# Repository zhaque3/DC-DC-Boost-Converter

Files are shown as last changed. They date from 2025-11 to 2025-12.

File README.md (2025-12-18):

# DC Boost Board

**Project:** DC Boost Board — a programmable boost converter for the University of Alberta EcoCar 2025 Prototype Vehicle. The vehicle (Sally) won first place at the Shell Eco Marathon 2025 in the Hydrogen Fuel Cell Prototype Category. 

**Purpose:** This board takes the vehicle's hydrogen fuel cell output voltage (nominally 24 V) and provides a controllable boosted output (typical target: 48 V) for the motor controller and motor. It includes measurement (voltage/current sensing), safety/protection (eFuses and monitoring), an MCU running FreeRTOS for control and telemetry, a simple local UI (OLED + push buttons), and CAN bus communication with other boards on the vehicle and wireless base station.

<p align="center">
  
</p>

---

## Table of contents

1. [Key features](#key-features)
2. [Hardware details](#hardware-details)
3. [FreeRTOS firmware overview](#freertos-firmware-overview-what-is-actually-running-on-board)

---

## Key features

* **LM5123** synchronous boost controller driving external mosfets for high-efficiency boost operation.
* Programmable dynamic voltage tuning controlled by MCU and local UI.
* Input/Output: nominal 24 V. The board is designed to output 48V but is capable of outputting 57. 
* **Input / output voltage sensing** and **current sensing** using ADCs and filtering. Firmware computes averaged values before publishing them to the display and logs.
* **TPS2623 eFuses** for controlled power delivery and overcurrent protection.
* **Local UI**: small OLED display (SSD1306) + push buttons for interaction. The display shows input/output voltages, currents, and an effeciency score.
* **FreeRTOS-based firmware** with multiple tasks handling ADC acquisition, DAC control for the tracking/virtual voltage (TRK) pin, LED/status handling, screen updates, and CAN bus communication.

---

## Hardware details

### Synchronous boost controller

* The Texas Instruments LM5123 is used as the switching controller. It drives external mosfets located at the back of the board. The 4 high and low side mosfets can be place on this board. 
* The ENABLE pin from the boost controller is driven by the MCU to allow safe startup/shutdown sequences (the code waits until input voltage is above a small threshold, then toggles ENABLE with a startup delay).
* The TRK (tracking) reference to the controller is driven by the MCU DAC to set the desired output. The firmware converts the `SET_VOLT` value to an appropriate DAC code.

### Sensing

* Voltage sensing is implemented with resistor dividers feeding ADCs.
* Current sensing is performed by hall-effect current sensors that outputs an ADC value to the MCU. 
* ADC sampling is done via DMA for efficiency

### Microcontroller

* The board is built around an STM32G91KUE6 microcontroller, which serves as the central control, sensing, and communication unit for the boost system.
* The MCU runs a FreeRTOS-based firmware architecture, allowing concurrent handling of power control, sensing, UI updates, and CAN communication without blocking critical control paths.

---

## FreeRTOS firmware overview

The firmware running on the DC Boost Board is FreeRTOS based and implemented entirely in `app_freertos.c`.  
The system is structured as a set of independent FreeRTOS tasks, each responsible for a specific functional domain: power control, sensing, user interface, and vehicle communication.

## Tasks (as implemented in `app_freertos.c`)

### DefaultTask (`StartDefaultTask`)

- Initializes the USB CDC device at startup for debug telemetry.
- Implements ENABLE pin sequencing for the LM5123 boost controller:
  - Continuously monitors input voltage.
  - Applies a one-time startup delay before asserting ENABLE once sufficient input voltage is detected.
  - Forces ENABLE low if input voltage falls below threshold and resets the startup sequence.
- Handles a push-button input to increment the output voltage setpoint (`SET_VOLT`) with bounds checking based on input voltage.

### ADC Conversion Task (`StartAdcConv`)

- Starts **ADC peripherals with DMA** for continuous sampling.
- Measures:
  - Input voltage
  - Output voltage
  - Input current
  - Output current
- Applies a 50-sample moving average to current measurements for noise reduction.
- Computes a real-time efficiency estimate using measured voltage and current values.
- Publishes computed values into CAN data structures and prints debug telemetry over USB CDC.

### Screen Print Task (`startScreenPrint`)

- Drives an **SSD1306 OLED display**.
- Displays:
  - Voltage setpoint
  - Input and output voltages
  - Input and output currents
  - Computed efficiency
- When a fault or lock condition is received over CAN, the display switches to an alarm state.

### TRK Pin Control Task (`StartTRKPin`)

- Controls the LM5123 TRK (tracking) pin using the on-chip DAC.
- Converts `SET_VOLT` into a proportional DAC output corresponding to the desired boost output voltage.

### Status LED Task (`StartStatusLED`)

- Controls multiple PWM-driven status LEDs using STM32 timer peripherals.
- LED indications include:
  - Boost ENABLE state
  - General system activity
- Continuously monitors the ENABLE GPIO to synchronize LED states with actual hardware behavior.

## CAN Bus Communication

- Uses the STM32 FDCAN peripheral for vehicle network communication.
- CAN reception is interrupt-driven and handled via the RX FIFO callback, with received frames pushed into FreeRTOS message queues.
- A dedicated receive task parses incoming CAN messages to:
  - Detect fault or lock conditions (e.g. hydrogen alarm states).
  - Update system behavior and UI state.
- A dedicated transmit task periodically publishes:
  - Input and output voltages
  - Input and output currents
  - Efficiency
  - System status flags
- CAN messaging enables real-time monitoring by other PCB's on the vehicle and the wireless telemetry system.

---

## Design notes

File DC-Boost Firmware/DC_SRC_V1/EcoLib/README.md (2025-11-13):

# EcoLib
A repository for various drivers and helpful functions to utilize a range of peripherals throughout EcoCar electrical projects

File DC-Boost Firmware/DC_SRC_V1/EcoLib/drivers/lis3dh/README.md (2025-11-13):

Copy the lis3dh_conf.h into your local include folder and 
add the inc and src folders into your project. The conf 
file will allow you to select the appropriate stm series
header file and configure the proper i2c handle.

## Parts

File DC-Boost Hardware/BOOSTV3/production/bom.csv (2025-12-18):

Designator | Footprint | Quantity | Value | LCSC Part #
C1, C2, C3 | CAP_PAN_10X20_PAN | 3 | 470u
C10, C18, C20, C21, C22, C23, C24, C28, C34, C35, C36, C37, C38, C39, C40, C43 | 0603 | 16 | 100n
C11 | 0603 | 1 | 47u
C12 | 0805 | 1 | 220p
C13, C32, C41 | 0603 | 3 | 10n
C14 | 0603 | 1 | 12n
C15 | 0603 | 1 | 470p
C16, C55 | 0603 | 2 | 0u1
C17, C49, C50 | 0603 | 3 | 22u
C19, C33 | 0603 | 2 | 4u7
C25, C26, C27 | CAP_YX_16X31P5_RUB | 3 | 470u
C29, C30, C31 | 1210 | 3 | 10u
C4, C5, C6, C7 | 0805 | 4 | 22u
C42, C44, C47, C48, C53, C54, C8, C9 | 0603 | 8 | 1u
C45, C46 | 0603 | 2 | 10u
C51, C52 | 0603 | 2 | 2n2
D1, D19, D2, D20 | D_SOD_123_M | 4 | MMSZ5226B-7-F
D10, D15, D17, D5 | 0603 | 4 | Red
D11, D12, D13, D14, D7, D8 | 0603 | 6 | BLUE
D16, D18, D6, D9 | 0603 | 4 | Green
D21, D24 | SOT-23 | 2 | BAT54S
D22 | D_SOD-123 | 1 | MMSZ5266BT1G
D23 | D_SOD-123 | 1 | MMSZ5257BT1G
D3 | SOT95P280X145-6N | 1 | USBLC6-2SC6
D4 | 0603 | 1 | Orange
FB1 | 0603 | 1 | 300R
IC1 | SOT65P210X110-5N | 1 | ESDALC6V1W5
J3 | USB_C_Receptacle_GCT_USB4105-xx-A_16P_TopMnt_Horizontal | 1 | USB_C_Receptacle_USB2.0_14P
J4 | IDC-STM32-Prog-Header_2x05_P2.54mm_Vertical | 1 | STM32-Prog-Header
J5 | Display_128x64_096_I2C | 1 | OLED
L1 | 3u3_induc | 1 | 1u5
Q1, Q2, Q3, Q4 | SOT-23-3_Adjusted | 4 | SI2302A-TPMSCT-ND
R1 | 0603 | 1 | 50k
R10, R2, R9 | 0603 | 3 | 100k
R11 | 1u5_res_ | 1 | 1u5
R12 | 0603 | 1 | R
R13, R14, R15, R17, R18, R19 | 0603 | 6 | 220R
R16, R20, R21, R22, R23, R34, R35, R38, R39 | 0603 | 9 | 7.5k
R24 | 0603 | 1 | 10k
R25, R26, R28 | 0603 | 3 | 1k
R27 | 0603 | 1 | 8k
R29, R30, R31 | 0603 | 3 | 1k2
R3, R8 | 0603 | 2 | 200k
R32, R36 | 0603 | 2 | 12k
R33, R37 | 0603 | 2 | 30k
R4 | 0603 | 1 | 15.4k
R40, R41 | 0603 | 2 | 4k7
R42 | 0603 | 1 | 27k
R43 | 0603 | 1 | 3k
R44 | 0603 | 1 | 3k6
R45 | 0603 | 1 | 68k
R46, R47 | 0603 | 2 | 10
R48 | WSLP3921L7000FEA | 1 | 1u5
R5 | 0603 | 1 | 6k98
R6 | 0603 | 1 | 28k
R7 | 0603 | 1 | 25k
SW1, SW2 | PinHeader_1x03_P2.54mm_Vertical | 2 | SW_SPDT
SW3 | SW_PUSH_6mm_H5mm | 1 | RESET
SW4 | SW_PUSH_6mm_H5mm | 1 | O/P Voltage Adjust
U1, U12 | SOIC-8_3.9x4.9mm_P1.27mm | 2 | ACS713xLCTR-30A
U10, U11, U4, U5, U6, U7, U8, U9 | PowerMosDFNHybrid | 8 | NTMFS4D0N08XT1G
U13 | SOIC-8_3.9x4.9mm_P1.27mm | 1 | MCP2542FD
U14 | QFN-32-1EP_5x5mm_P0.5mm_EP3.45x3.45mm | 1 | STM32G491KEUx
U15 | SOT-223-3_TabPin2 | 1 | AZ1117IH-5.0
U16 | SOT-223-3_TabPin2 | 1 | AZ1117IH-3.3
U17, U18 | TI_SO-PowerPAD-8 | 2 | TPS259631
U19 | DB7W2-Male | 1 | ~
U2, U20 | SOIC-8_3.9x4.9mm_P1.27mm | 2 | MCP6007
U21, U22 | PowerPole15-45BoardEdge2x1 | 2 | ~
U3 | RGR0020C-MFG | 1 | LM51231QRGRRQ1
X1 | Crystal_SMD_3225-4Pin_3.2x2.5mm | 1 | OXETDLJANF-8MHZ

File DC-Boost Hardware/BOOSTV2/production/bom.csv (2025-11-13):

Designator | Footprint | Quantity | Value | LCSC Part #
C1, C2, C3 | CAP_PAN_10X20_PAN | 3 | 470u
C10, C18, C20, C21, C22, C23, C24, C28, C34, C35, C36, C37, C38, C39, C40, C43 | 0603 | 16 | 100n
C11 | 0603 | 1 | 330n
C12 | 0805 | 1 | 330p
C13, C32, C41 | 0603 | 3 | 10n
C14 | 0603 | 1 | 56n
C15 | 0603 | 1 | 470p
C16, C55 | 0603 | 2 | 0u1
C17, C49, C50 | 0603 | 3 | 22u
C19, C33 | 0603 | 2 | 4u7
C25, C26, C27 | CAP_YX_16X31P5_RUB | 3 | 470u
C29, C30, C31 | 1210 | 3 | 10u
C4, C5, C6, C7 | 0805 | 4 | 22u
C42, C44, C47, C48, C53, C54, C8, C9 | 0603 | 8 | 1u
C45, C46 | 0603 | 2 | 10u
C51, C52 | 0603 | 2 | 2n2
D1, D19, D2, D20 | D_SOD_123_M | 4 | MMSZ5226B-7-F
D10, D15, D17, D9 | 0603 | 4 | Red
D11, D12, D13, D14 | 0603 | 4 | BLUE
D16, D18 | 0603 | 2 | Green
D21, D24 | SOT-23 | 2 | BAT54S
D22 | D_SOD-123 | 1 | MMSZ5266BT1G
D23 | D_SOD-123 | 1 | MMSZ5257BT1G
D3 | SOT95P280X145-6N | 1 | USBLC6-2SC6
D4, D5, D6, D8 | 0603 | 4 | Amber
D7 | 0603 | 1 | LED
FB1 | 0603 | 1 | 300R
IC1 | SOT65P210X110-5N | 1 | ESDALC6V1W5
J1, J2 | PHOENIX_1017521 | 2 | PHNX_CONN_1017521
J3 | USB_C_Receptacle_GCT_USB4105-xx-A_16P_TopMnt_Horizontal | 1 | USB_C_Receptacle_USB2.0_14P
J4 | IDC-STM32-Prog-Header_2x05_P2.54mm_Vertical | 1 | STM32-Prog-Header
J5 | Display_128x64_096_I2C | 1 | OLED
L1 | L_Kemet_3u3 | 1 | MPXV1D2213L3R3
Q1, Q2, Q3, Q4 | SOT-23-3_Adjusted | 4 | SI2302A-TPMSCT-ND
R1 | 0603 | 1 | 221k
R10, R2, R9 | 0603 | 3 | 100k
R11 | CSS2H3920RL700F | 1 | 1m5
R12 | 0603 | 1 | R
R13, R14, R15, R17, R18, R19, R22, R23 | 0603 | 8 | 220R
R16 | 0603 | 1 | 140R
R20 | 0603 | 1 | 820
R21, R34, R35, R38, R39 | 0603 | 5 | 270
R24 | 0603 | 1 | 10k
R25, R26, R28 | 0603 | 3 | 1k
R27 | 0603 | 1 | 8k
R29, R30, R31 | 0603 | 3 | 1k2
R3, R8 | 0603 | 2 | 200k
R32, R36 | 0603 | 2 | 12k
R33, R37 | 0603 | 2 | 30k
R4 | 0603 | 1 | 5k
R40, R41 | 0603 | 2 | 4k7
R42 | 0603 | 1 | 27k
R43 | 0603 | 1 | 3k
R44 | 0603 | 1 | 3k6
R45 | 0603 | 1 | 68k
R46, R47 | 0603 | 2 | 10
R5 | 0603 | 1 | 6k98
R6 | 0603 | 1 | 28k
R7 | 0603 | 1 | 25k
SW1, SW2 | PinHeader_1x03_P2.54mm_Vertical | 2 | SW_SPDT
SW3 | SW_PUSH_6mm_H5mm | 1 | RESET
SW4 | SW_PUSH_6mm_H5mm | 1 | GPIO
U1, U12 | SOIC-8_3.9x4.9mm_P1.27mm | 2 | ACS713xLCTR-30A
U10, U11, U4, U5, U6, U7, U8, U9 | PowerMosDFNHybrid | 8 | NTMFS4D0N08XT1G
U13 | SOIC-8_3.9x4.9mm_P1.27mm | 1 | MCP2542FD
U14 | QFN-32-1EP_5x5mm_P0.5mm_EP3.45x3.45mm | 1 | STM32G491KEUx
U15 | SOT-223-3_TabPin2 | 1 | AZ1117IH-5.0
U16 | SOT-223-3_TabPin2 | 1 | AZ1117IH-3.3
U17, U18 | TI_SO-PowerPAD-8 | 2 | TPS259631
U19 | DB7W2-Male | 1 | ~
U2, U20 | SOIC-8_3.9x4.9mm_P1.27mm | 2 | MCP6007
U3 | RGR0020C-MFG | 1 | LM51231QRGRRQ1
X1 | Crystal_SMD_3225-4Pin_3.2x2.5mm | 1 | OXETDLJANF-8MHZ

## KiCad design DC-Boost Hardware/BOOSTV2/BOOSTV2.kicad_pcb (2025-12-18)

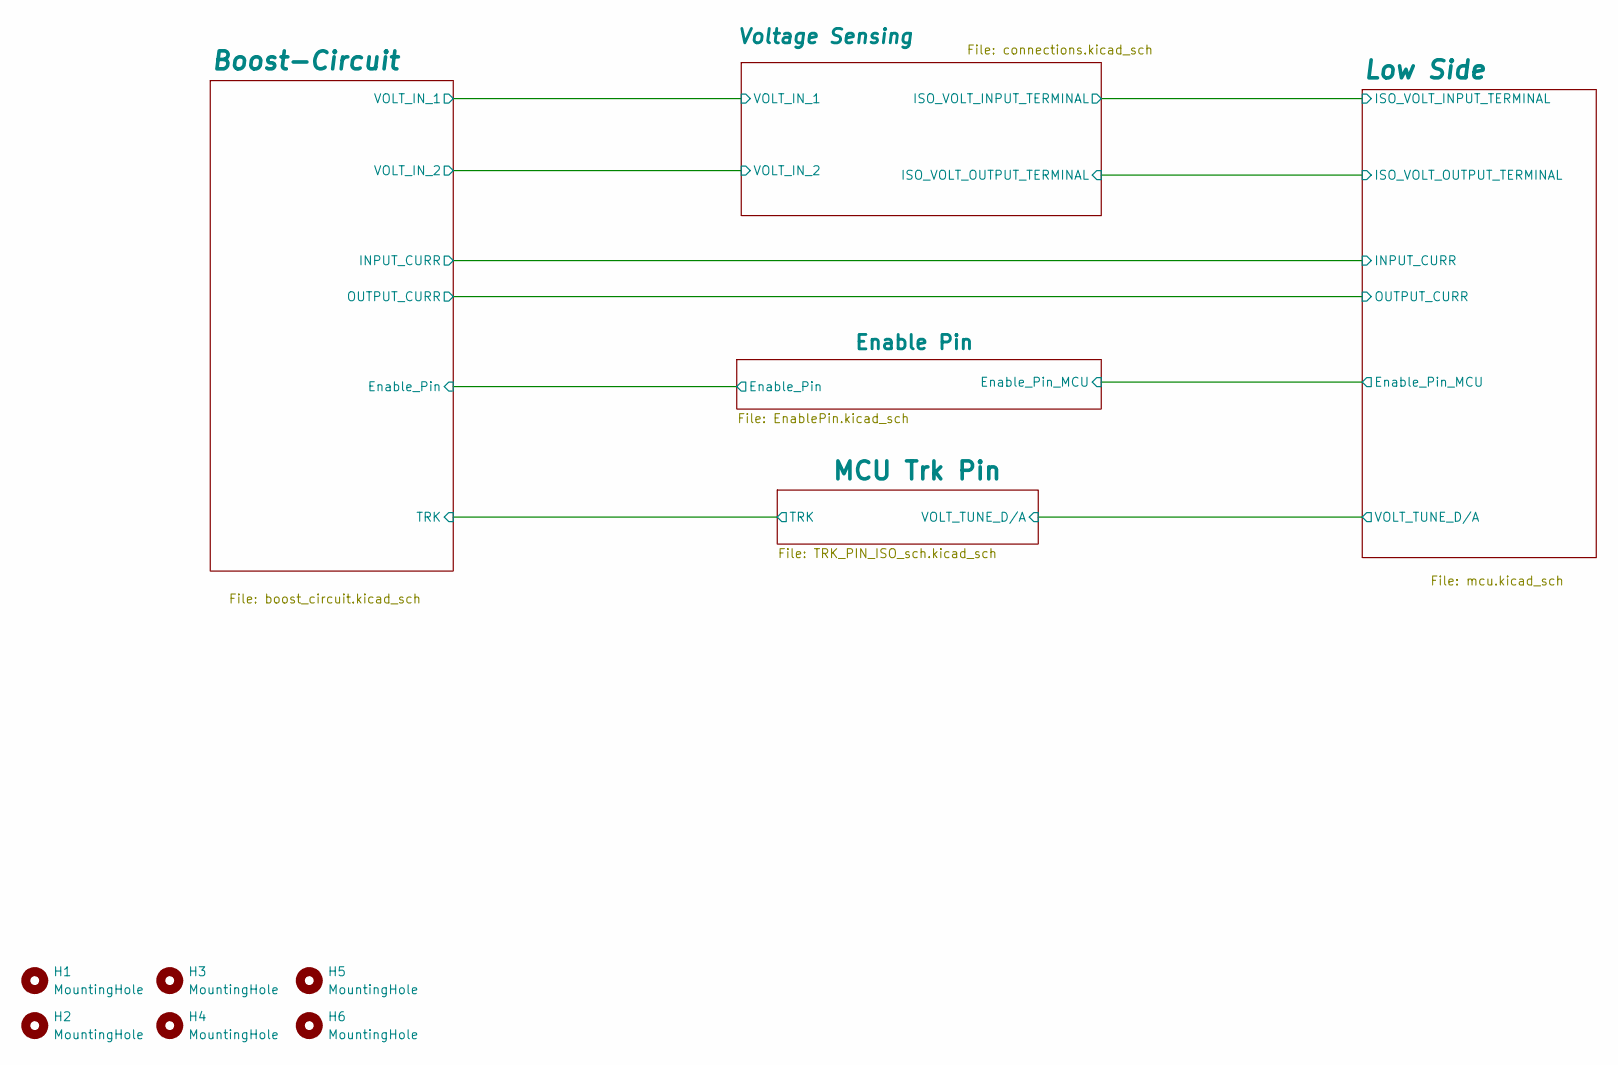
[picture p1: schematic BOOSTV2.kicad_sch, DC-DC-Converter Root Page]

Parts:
H1, H2, H3, H4, H5, H6: MountingHole; MountingHole_3.5mm

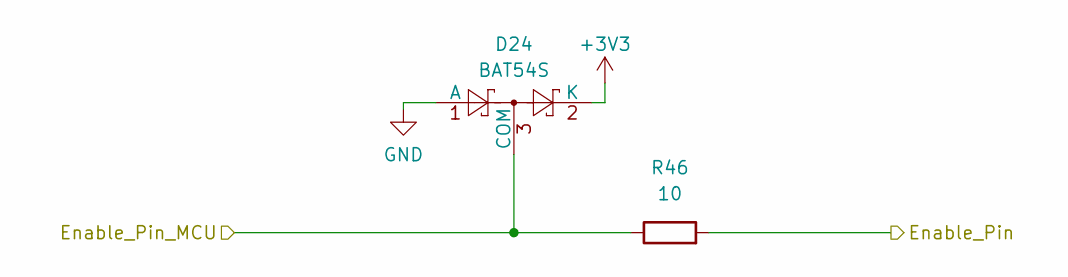
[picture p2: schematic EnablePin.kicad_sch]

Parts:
D24: BAT54S; SOT-23
R46: 10; R_0603_1608Metric

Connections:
+3V3: D24.2 (K); also elsewhere on the board
/Boost-Circuit/Enable_Pin: R46.2; also elsewhere on the board
/Enable Pin/Enable_Pin_MCU: D24.3 (COM), R46.1; also elsewhere on the board
GND: D24.1 (A); also elsewhere on the board

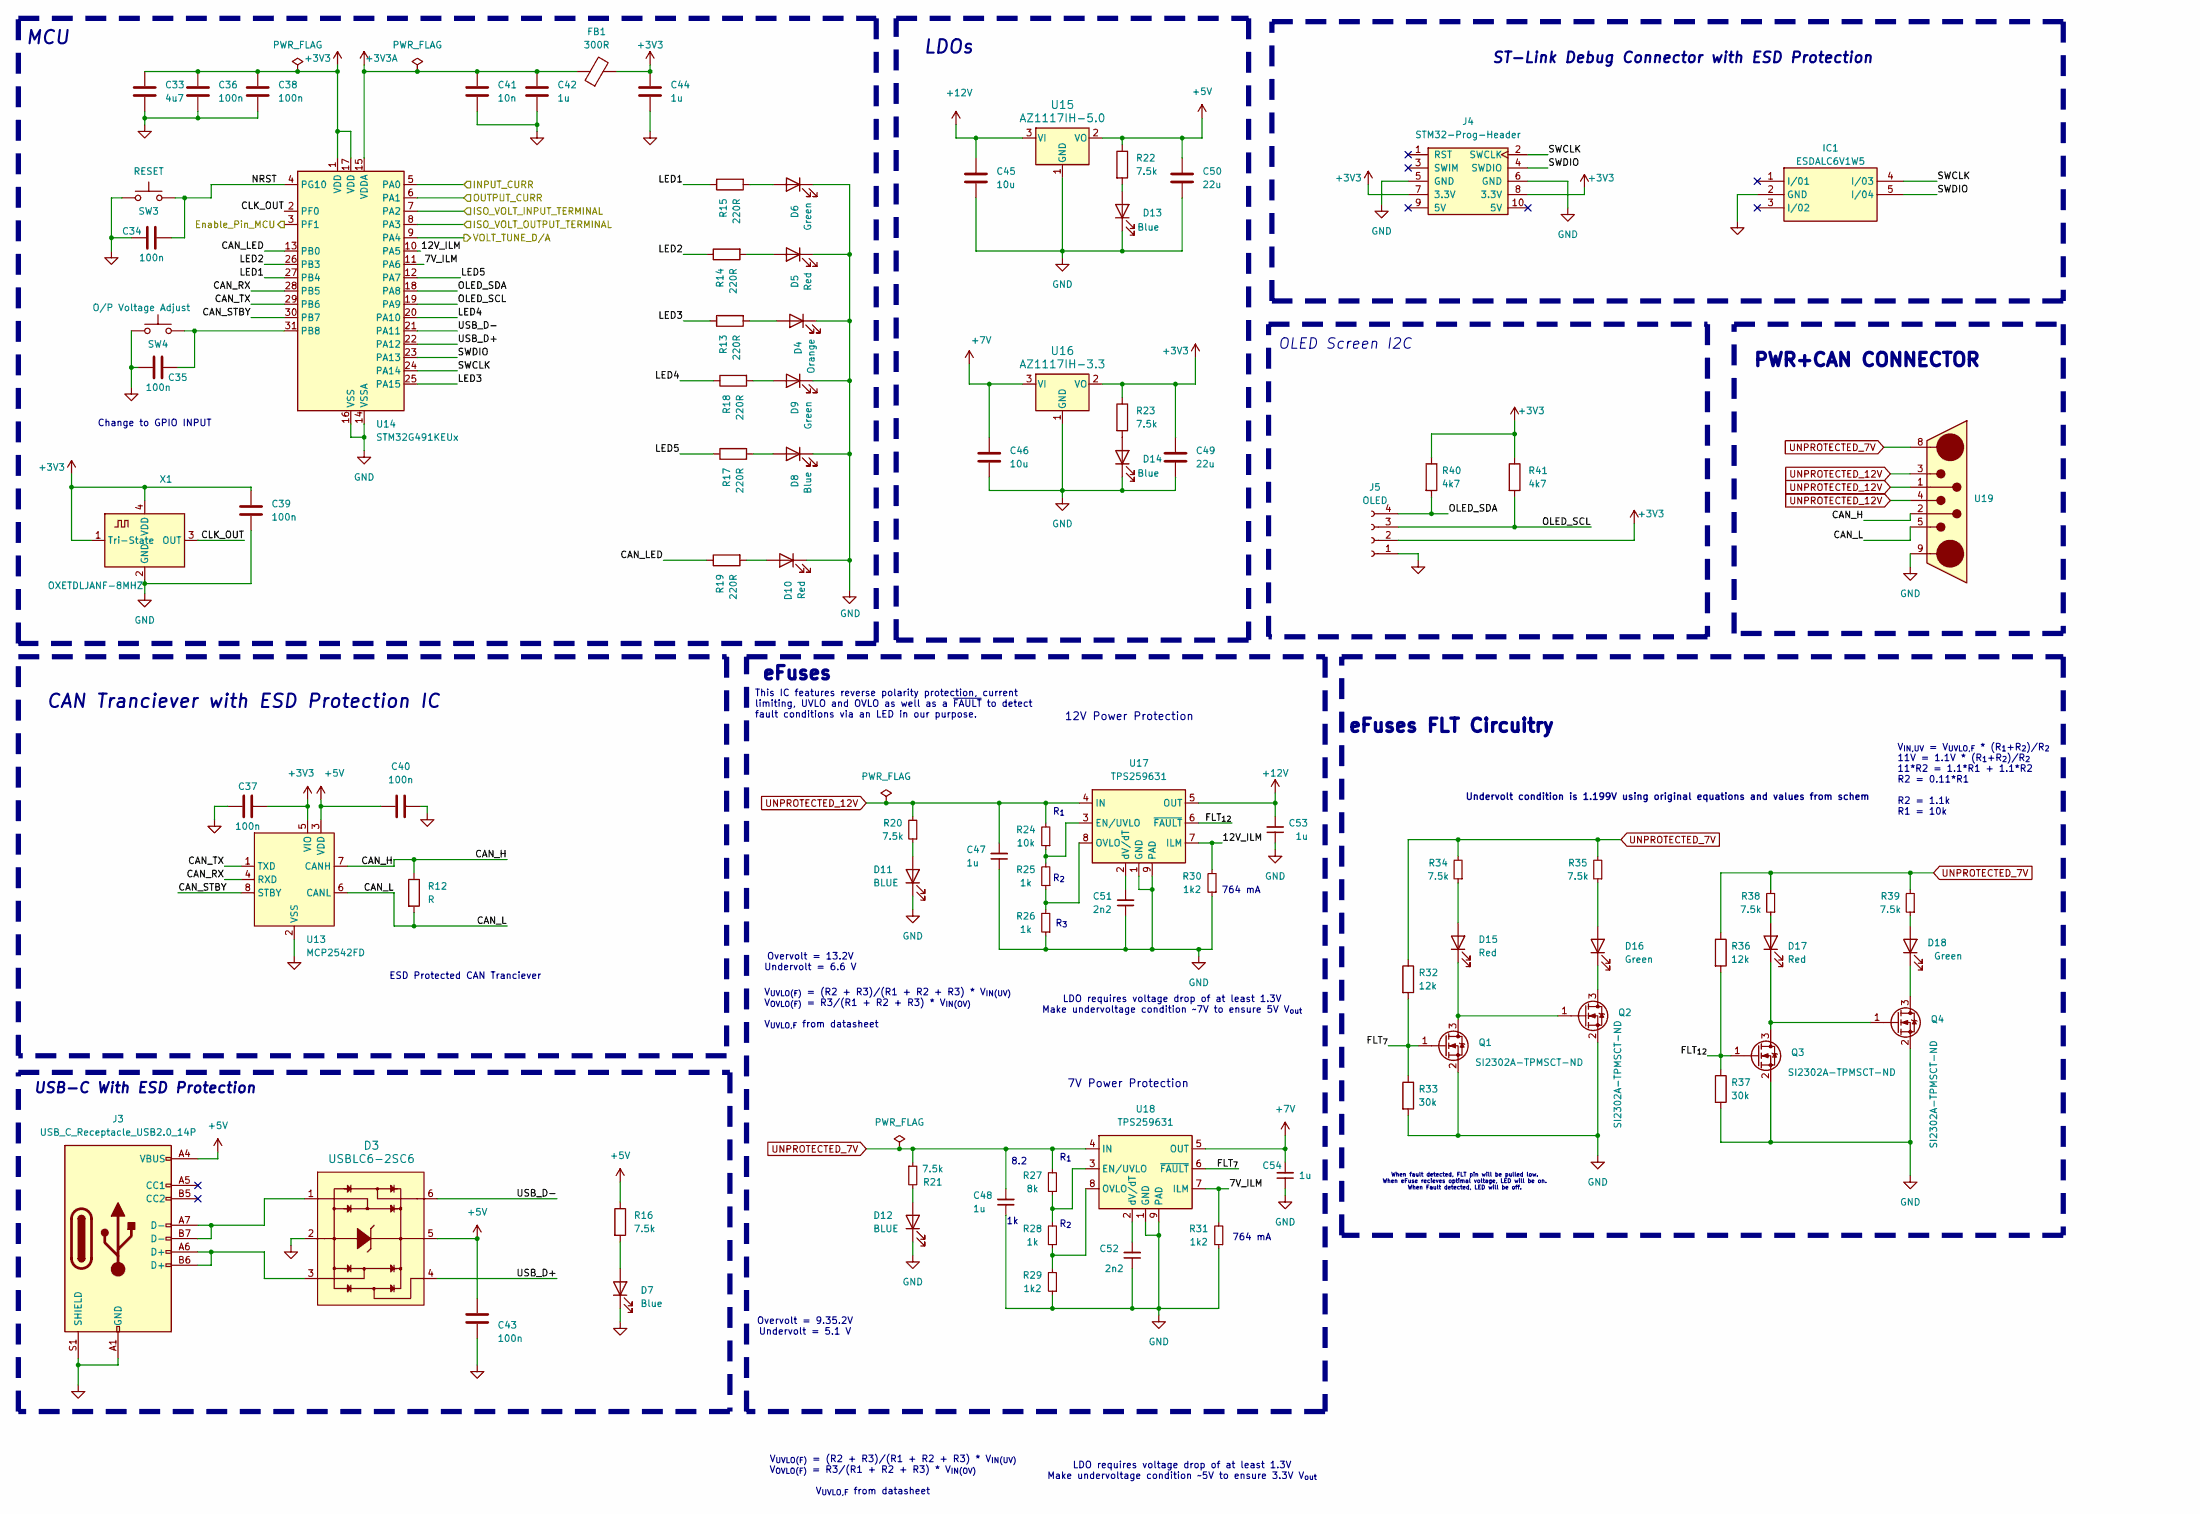
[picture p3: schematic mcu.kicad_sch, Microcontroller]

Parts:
C33: 4u7; C_0603_1608Metric; JLCPCB Part#(Optional) C96446
C34, C35, C36, C37, C38, C40, C43: 100n; C_0603_1608Metric; JLCPCB Part#(Optional) C1525
C39: 100n; C_0603_1608Metric
C41: 10n; C_0603_1608Metric; JLCPCB Part#(Optional) C96446
C42, C44: 1u; C_0603_1608Metric; JLCPCB Part#(Optional) C28323
C45, C46: 10u; C_0603_1608Metric
C47, C48, C53, C54: 1u; C_0603_1608Metric; Part# C15849
C49, C50: 22u; C_0603_1608Metric
C51, C52: 2n2; C_0603_1608Metric; Part# C1604
D3: USBLC6-2SC6; SOT95P280X145-6N; Digikey # 497-5235-1-ND
D4: Orange; LED_0603_1608Metric
D5, D10: Red; LED_0603_1608Metric
D6, D9: Green; LED_0603_1608Metric
D7, D8, D13, D14: Blue; LED_0603_1608Metric
D11, D12: BLUE; LED_0603_1608Metric; Part# C72041
D15, D17: Red; LED_0603_1608Metric; Part# C72043
D16, D18: Green; LED_0603_1608Metric; Part# C72043
FB1: 300R; L_0603_1608Metric; Digikey # 1934-1474-1-ND
IC1: ESDALC6V1W5; SOT65P210X110-5N; JLCPCB Part#(Optional) C2827626
J3: USB_C_Receptacle_USB2.0_14P; USB_C_Receptacle_GCT_USB4105-xx-A_16P_TopMnt_Horizontal
J4: STM32-Prog-Header; IDC-STM32-Prog-Header_2x05_P2.54mm_Vertical
J5: OLED; Display_128x64_096_I2C
Q1, Q2, Q3, Q4: SI2302A-TPMSCT-ND; SOT-23-3_Adjusted; Part# SI2302A-TPMSCT-ND
R12: R; R_0603_1608Metric
R13, R14, R15, R17, R18, R19: 220R; R_0603_1608Metric
R16, R22, R23: 7.5k; R_0603_1608Metric
R20: 7.5k; R_0603_1608Metric; Part# C23253
R21, R34, R35, R38, R39: 7.5k; R_0603_1608Metric; Part# C22966
R24: 10k; R_0603_1608Metric
R25, R26, R28: 1k; R_0603_1608Metric
R27: 8k; R_0603_1608Metric
R29, R30, R31: 1k2; R_0603_1608Metric
R32, R36: 12k; R_0603_1608Metric
R33, R37: 30k; R_0603_1608Metric
R40, R41: 4k7; R_0603_1608Metric
SW3: RESET; SW_PUSH_6mm_H5mm; Part # C2689510
SW4: O/P Voltage Adjust; SW_PUSH_6mm_H5mm; Part # C2689510
U13: MCP2542FD; SOIC-8_3.9x4.9mm_P1.27mm
U14: STM32G491KEUx; QFN-32-1EP_5x5mm_P0.5mm_EP3.45x3.45mm
U15: AZ1117IH-5.0; SOT-223-3_TabPin2
U16: AZ1117IH-3.3; SOT-223-3_TabPin2
U17, U18: TPS259631; TI_SO-PowerPAD-8
U19: DB7W2-Male
X1: OXETDLJANF-8MHZ; Crystal_SMD_3225-4Pin_3.2x2.5mm

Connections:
+3V3: C33.1, C36.1, C37.2, C38.1, C39.1, C44.1, C49.1, FB1.2, J4.7 (3.3V), J4.8 (3.3V), J5.2, R23.1, R40.1, R41.1, U13.5 (VIO), U14.1 (VDD), U14.17 (VDD), U16.2 (VO), X1.1 (Tri-State), X1.4 (VDD); also elsewhere on the board
+3V3A: C41.1, C42.1, FB1.1, U14.15 (VDDA)
+5V: C40.2, C43.2, C50.1, D3.5, J3.A4 (VBUS), J3.A9 (VBUS), J3.B4 (VBUS), J3.B9 (VBUS), R16.1, R22.1, U13.3 (VDD), U15.2 (VO); also elsewhere on the board
+7V: C46.1, C54.2, U16.3 (VI), U18.5 (OUT)
+12V: C45.1, C53.2, U15.3 (VI), U17.5 (OUT)
/Boost-Circuit/INPUT_CURR: U14.5 (PA0); also elsewhere on the board
/Boost-Circuit/OUTPUT_CURR: U14.6 (PA1); also elsewhere on the board
/Enable Pin/Enable_Pin_MCU: U14.3 (PF1); also elsewhere on the board
/Low Side/7V_ILM: R31.2, U14.11 (PA6), U18.7 (ILM)
/Low Side/12V_ILM: R30.2, U14.10 (PA5), U17.7 (ILM)
/Low Side/CAN_H: R12.1, U13.7 (CANH), U19.2
/Low Side/CAN_L: R12.2, U13.6 (CANL), U19.5
/Low Side/CAN_LED: R19.1, U14.13 (PB0)
/Low Side/CAN_RX: U13.4 (RXD), U14.28 (PB5)
/Low Side/CAN_STBY: U13.8 (STBY), U14.30 (PB7)
/Low Side/CAN_TX: U13.1 (TXD), U14.29 (PB6)
/Low Side/CLK_OUT: U14.2 (PF0), X1.3 (OUT)
/Low Side/FLT_{7}: Q1.1 (G), R32.2, R33.1, U18.6 (~FAULT)
/Low Side/FLT_{12}: Q3.1 (G), R36.2, R37.1, U17.6 (~FAULT)
/Low Side/ISO_VOLT_INPUT_TERMINAL: U14.7 (PA2); also elsewhere on the board
/Low Side/ISO_VOLT_OUTPUT_TERMINAL: U14.8 (PA3); also elsewhere on the board
/Low Side/LED1: R15.1, U14.27 (PB4)
/Low Side/LED2: R14.1, U14.26 (PB3)
/Low Side/LED3: R13.1, U14.25 (PA15)
/Low Side/LED4: R18.1, U14.20 (PA10)
/Low Side/LED5: R17.1, U14.12 (PA7)
/Low Side/NRST: C34.2, SW3.2, U14.4 (PG10)
/Low Side/OLED_SCL: J5.3, R41.2, U14.19 (PA9)
/Low Side/OLED_SDA: J5.4, R40.2, U14.18 (PA8)
/Low Side/SWCLK: IC1.4 (I/03), J4.2 (SWCLK), U14.24 (PA14)
/Low Side/SWDIO: IC1.5 (I/04), J4.4 (SWDIO), U14.23 (PA13)
/Low Side/USB_D+: D3.4, U14.22 (PA12)
/Low Side/USB_D-: D3.6, U14.21 (PA11)
/Low Side/VOLT_TUNE_D/A: U14.9 (PA4); also elsewhere on the board
GND: C33.2, C34.1, C35.1, C36.2, C37.1, C38.2, C39.2, C40.1, C41.2, C42.2, C43.1, C44.2, C45.2, C46.2, C47.1, C48.1, C49.2, C50.2, C51.1, C52.1, C53.1, C54.1, D3.2, D4.1 (K), D5.1 (K), D6.1 (K), D7.1 (K), D8.1 (K), D9.1 (K), D10.1 (K), D11.1 (K), D12.1 (K), D13.1 (K), D14.1 (K), IC1.2 (GND), J3.A1 (GND), J3.A12 (GND), J3.B1 (GND), J3.B12 (GND), J3.S1 (SHIELD), J4.5 (GND), J4.6 (GND), J5.1, Q1.2 (S), Q2.2 (S), Q3.2 (S), Q4.2 (S), R26.1, R29.1, R30.1, R31.1, R33.2, R37.2, SW3.1, SW4.2, U13.2 (VSS), U14.14 (VSSA), U14.16 (VSS), U14.32 (VSS), U14.33 (VSS), U15.1 (GND), U16.1 (GND), U17.1 (GND), U17.9 (PAD), U18.1 (GND), U18.9 (PAD), U19.9, X1.2 (GND); also elsewhere on the board
unnamed: D3.1, J3.A7 (D-), J3.B7 (D-)
unnamed: D3.3, J3.A6 (D+), J3.B6 (D+)
unnamed: D4.2 (A), R13.2
unnamed: D5.2 (A), R14.2
unnamed: D6.2 (A), R15.2
unnamed: D7.2 (A), R16.2
unnamed: D8.2 (A), R17.2
unnamed: D9.2 (A), R18.2
unnamed: D10.2 (A), R19.2
unnamed: D11.2 (A), R20.1
unnamed: D12.2 (A), R21.2
unnamed: D13.2 (A), R22.2
unnamed: D14.2 (A), R23.2
unnamed: D15.2 (A), R34.1
unnamed: D15.1 (K), Q1.3 (D), Q2.1 (G)
unnamed: D16.2 (A), R35.1
unnamed: D16.1 (K), Q2.3 (D)
unnamed: D17.2 (A), R38.1
unnamed: D17.1 (K), Q3.3 (D), Q4.1 (G)
unnamed: D18.2 (A), R39.1
unnamed: D18.1 (K), Q4.3 (D)
unnamed: C35.2, SW4.1, U14.31 (PB8)
unnamed: R24.1, R25.2, U17.3 (EN/UVLO)
unnamed: R25.1, R26.2, U17.8 (OVLO)
unnamed: C51.2, U17.2 (dV/dT)
unnamed: R27.1, R28.2, U18.3 (EN/UVLO)
unnamed: R28.1, R29.2, U18.8 (OVLO)
unnamed: C52.2, U18.2 (dV/dT)
UNPROTECTED_7V: C48.2, R21.1, R27.2, R32.1, R34.2, R35.2, R36.1, R38.2, R39.2, U18.4 (IN), U19.8
UNPROTECTED_12V: C47.2, R20.2, R24.2, U17.4 (IN), U19.1, U19.3, U19.4

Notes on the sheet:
764 mA
V_{UVLO(F)} = (R2 + R3)/(R1 + R2 + R3) * V_{IN(UV)} V_{OVLO(F)} = R3/(R1 + R2 + R3) * V_{IN(OV)} V_{UVLO,F} from datasheet
V_{IN,UV} = V_{UVLO,F} * (R_{1}+R_{2})/R_{2} 11V = 1.1V * (R_{1}+R_{2})/R_{2} 11*R2 = 1.1*R1 + 1.1*R2 R2 = 0.11*R1 R2 = 1.1k R1 = 10k
MCU
Undervolt condition is 1.199V using original equations and values from schem
LDO requires voltage drop of at least 1.3V Make undervoltage condition ~7V to ensure 5V V_{out}
Overvolt = 13.2V Undervolt = 6.6 V
PWR+CAN CONNECTOR
ST-Link Debug Connector with ESD Protection
8.2
USB-C With ESD Protection
R_{1}
LDOs
CAN Tranciever with ESD Protection IC
R_{2}
LDO requires voltage drop of at least 1.3V Make undervoltage condition ~5V to ensure 3.3V V_{out}
When fault detected, FLT pin will be pulled low. When eFuse recieves optimal voltage, LED will be on. When Fault detected, LED will be off.
Change to GPIO INPUT
eFuses
ESD Protected CAN Tranciever
This IC features reverse polarity protection, current limiting, UVLO and OVLO as well as a ~{FAULT} to detect fault conditions via an LED in our purpose.
V_{UVLO(F)} = (R2 + R3)/(R1 + R2 + R3) * V_{IN(UV)} V_{OVLO(F)} = R3/(R1 + R2 + R3) * V_{IN(OV)} V_{UVLO,F} from datasheet
Overvolt = 9.35.2V Undervolt = 5.1 V
7V Power Protection
OLED Screen I2C
R_{3}
12V Power Protection
eFuses FLT Circuitry

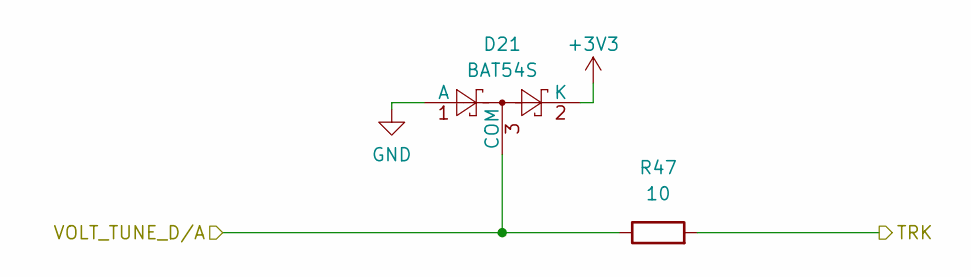
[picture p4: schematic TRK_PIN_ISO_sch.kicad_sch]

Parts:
D21: BAT54S; SOT-23
R47: 10; R_0603_1608Metric

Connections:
+3V3: D21.2 (K); also elsewhere on the board
/Boost-Circuit/TRK: R47.2; also elsewhere on the board
/Low Side/VOLT_TUNE_D/A: D21.3 (COM), R47.1; also elsewhere on the board
GND: D21.1 (A); also elsewhere on the board

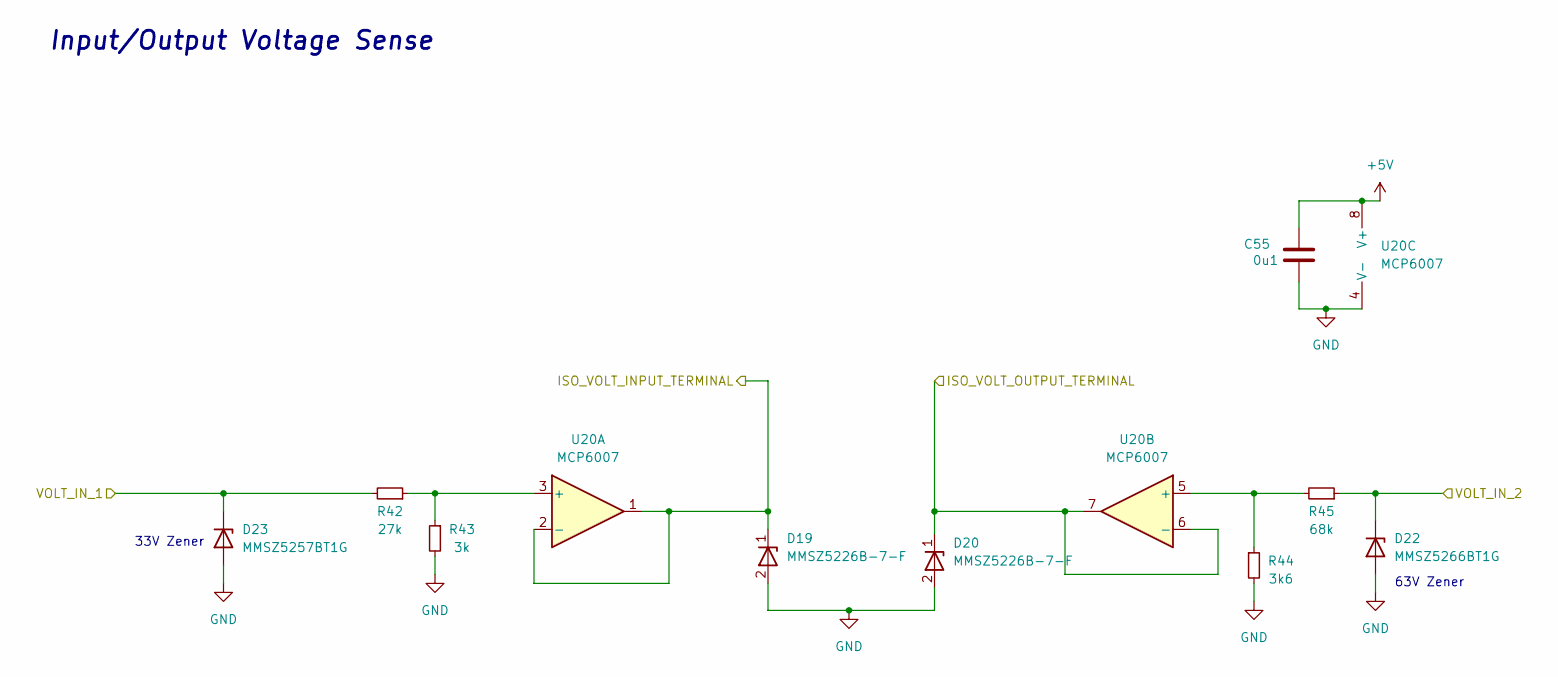
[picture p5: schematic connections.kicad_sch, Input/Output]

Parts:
C55: 0u1; C_0603_1608Metric
D19, D20: MMSZ5226B-7-F; D_SOD_123_M; Part# C155250
D22: MMSZ5266BT1G; D_SOD-123
D23: MMSZ5257BT1G; D_SOD-123
R42: 27k; R_0603_1608Metric
R43: 3k; R_0603_1608Metric; Part# C25811
R44: 3k6; R_0603_1608Metric
R45: 68k; R_0603_1608Metric
U20: MCP6007; SOIC-8_3.9x4.9mm_P1.27mm

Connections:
+5V: C55.1, U20.8 (V+); also elsewhere on the board
/Boost-Circuit/VOLT_IN_1: D23.1 (K), R42.2; also elsewhere on the board
/Boost-Circuit/VOLT_IN_2: D22.1 (K), R45.1; also elsewhere on the board
/Low Side/ISO_VOLT_INPUT_TERMINAL: D19.1, U20.1, U20.2 (-); also elsewhere on the board
/Low Side/ISO_VOLT_OUTPUT_TERMINAL: D20.1, U20.6 (-), U20.7; also elsewhere on the board
GND: C55.2, D19.2, D20.2, D22.2 (A), D23.2 (A), R43.2, R44.2, U20.4 (V-); also elsewhere on the board
unnamed: R42.1, R43.1, U20.3 (+)
unnamed: R44.1, R45.2, U20.5 (+)

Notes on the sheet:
33V Zener
Input/Output Voltage Sense
63V Zener

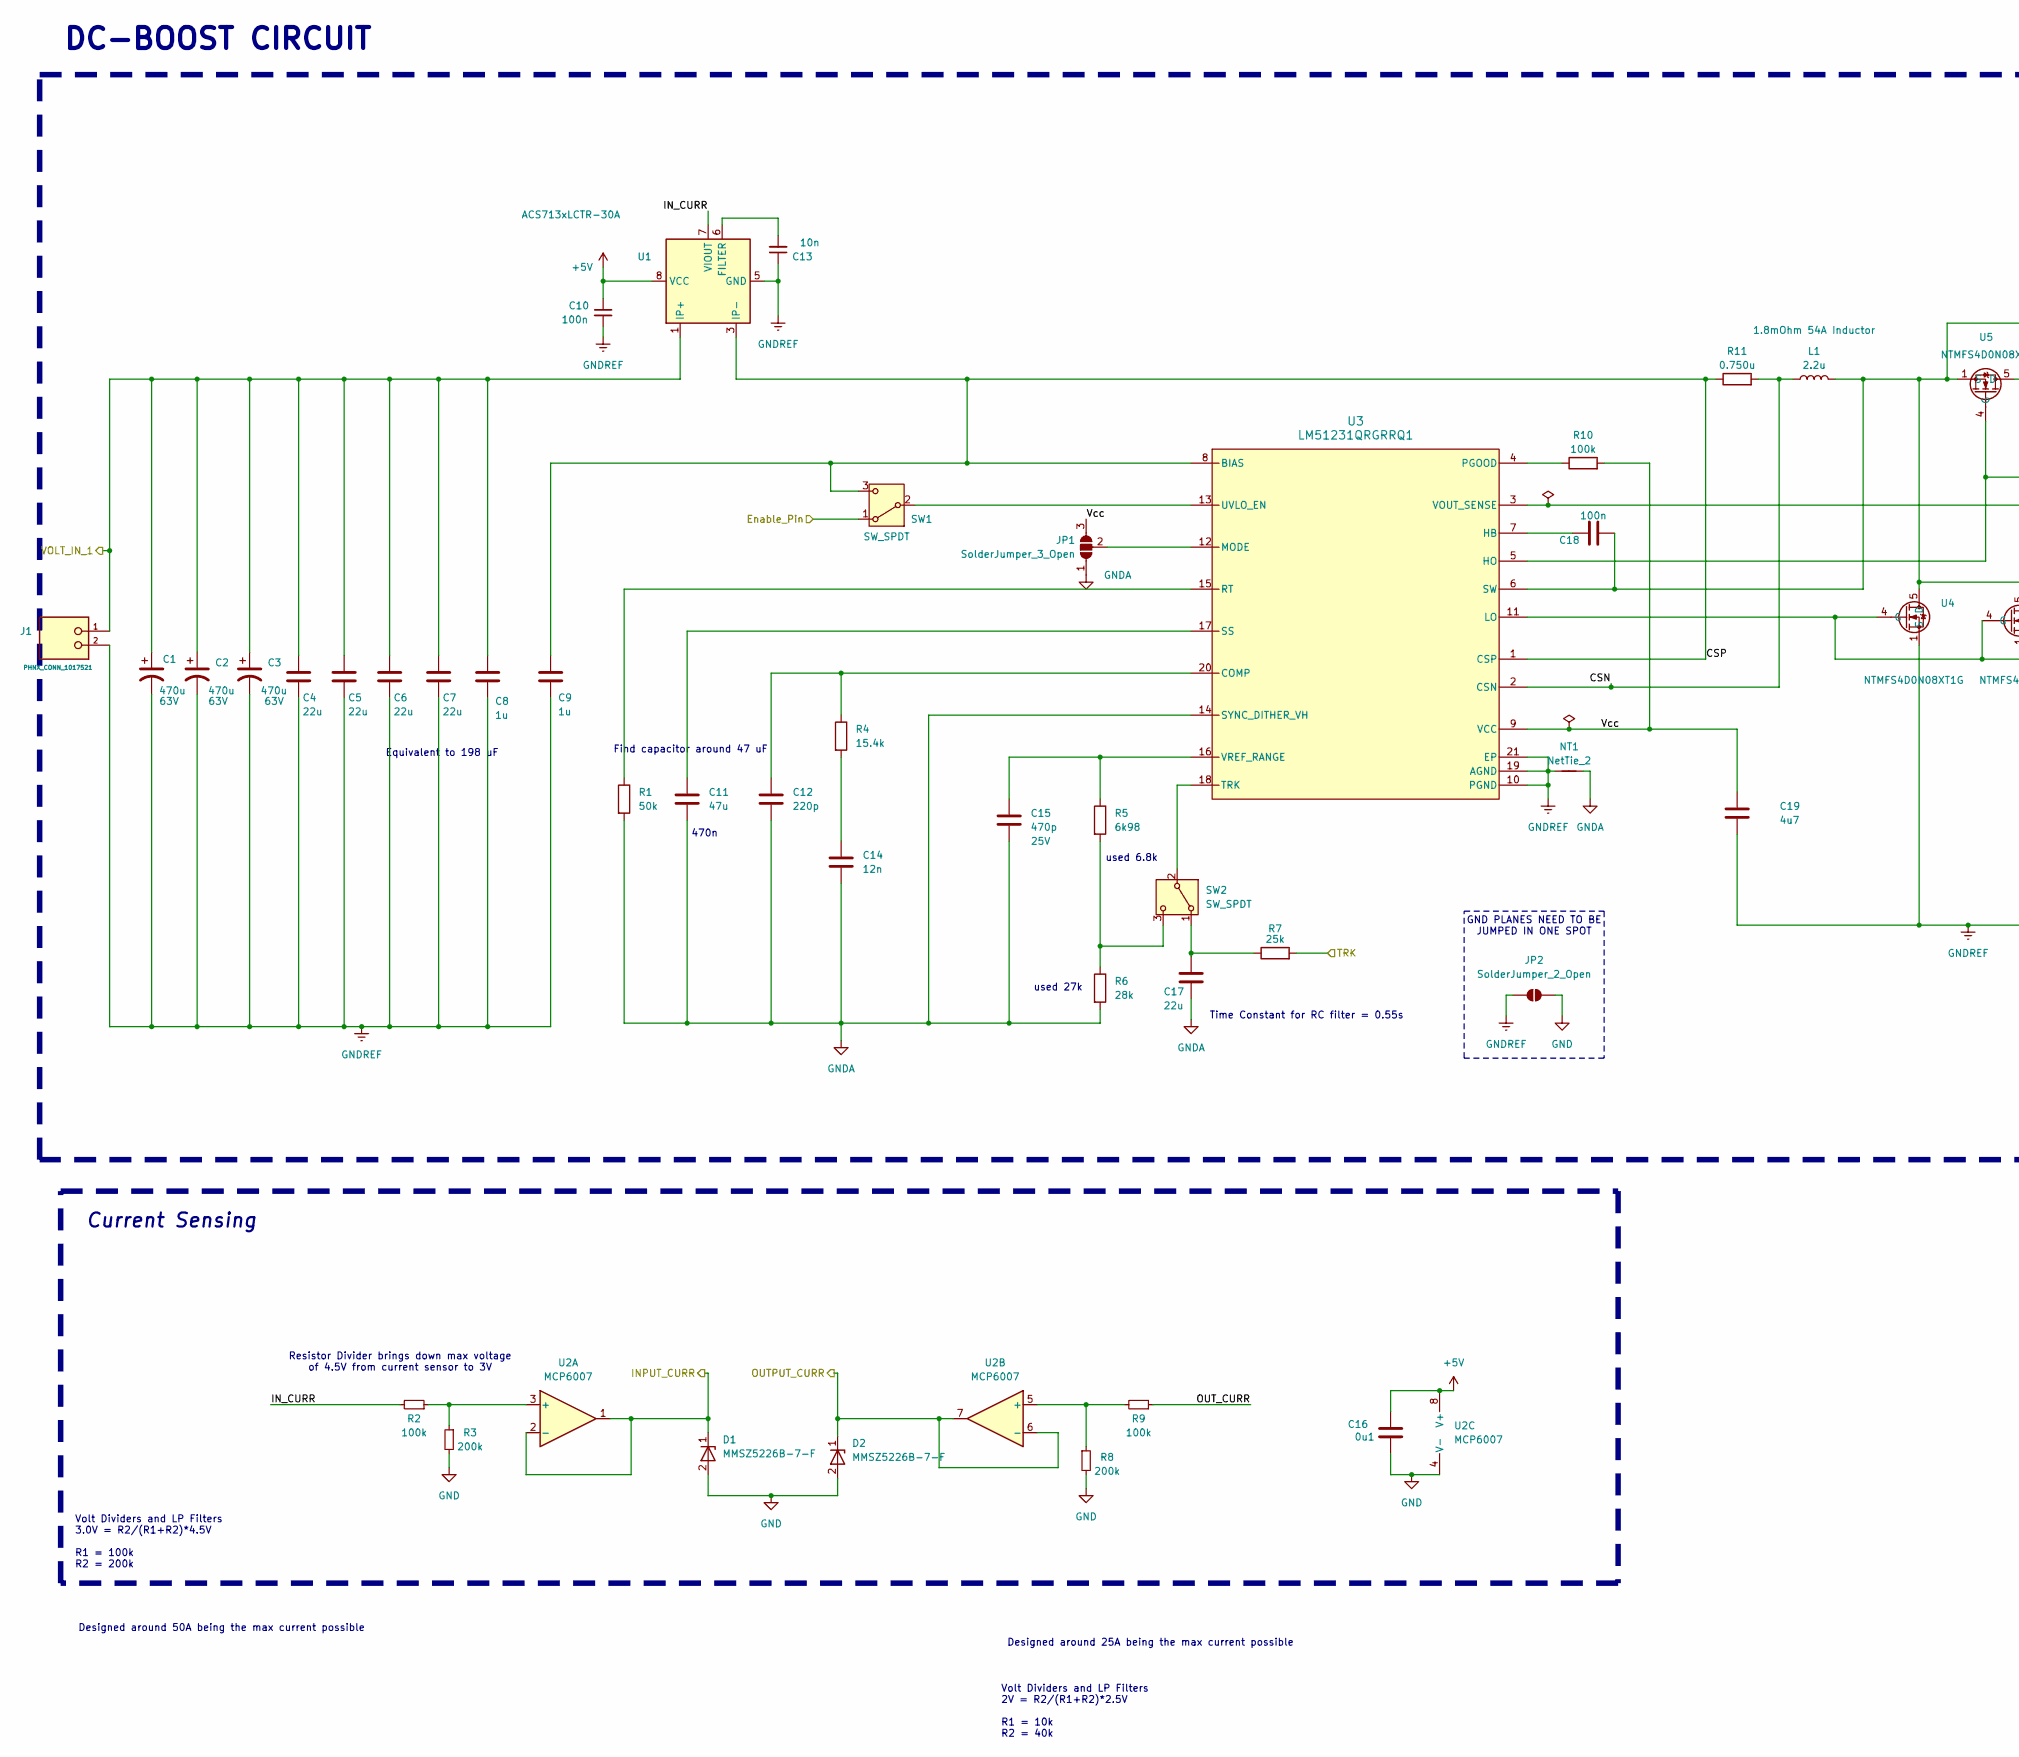
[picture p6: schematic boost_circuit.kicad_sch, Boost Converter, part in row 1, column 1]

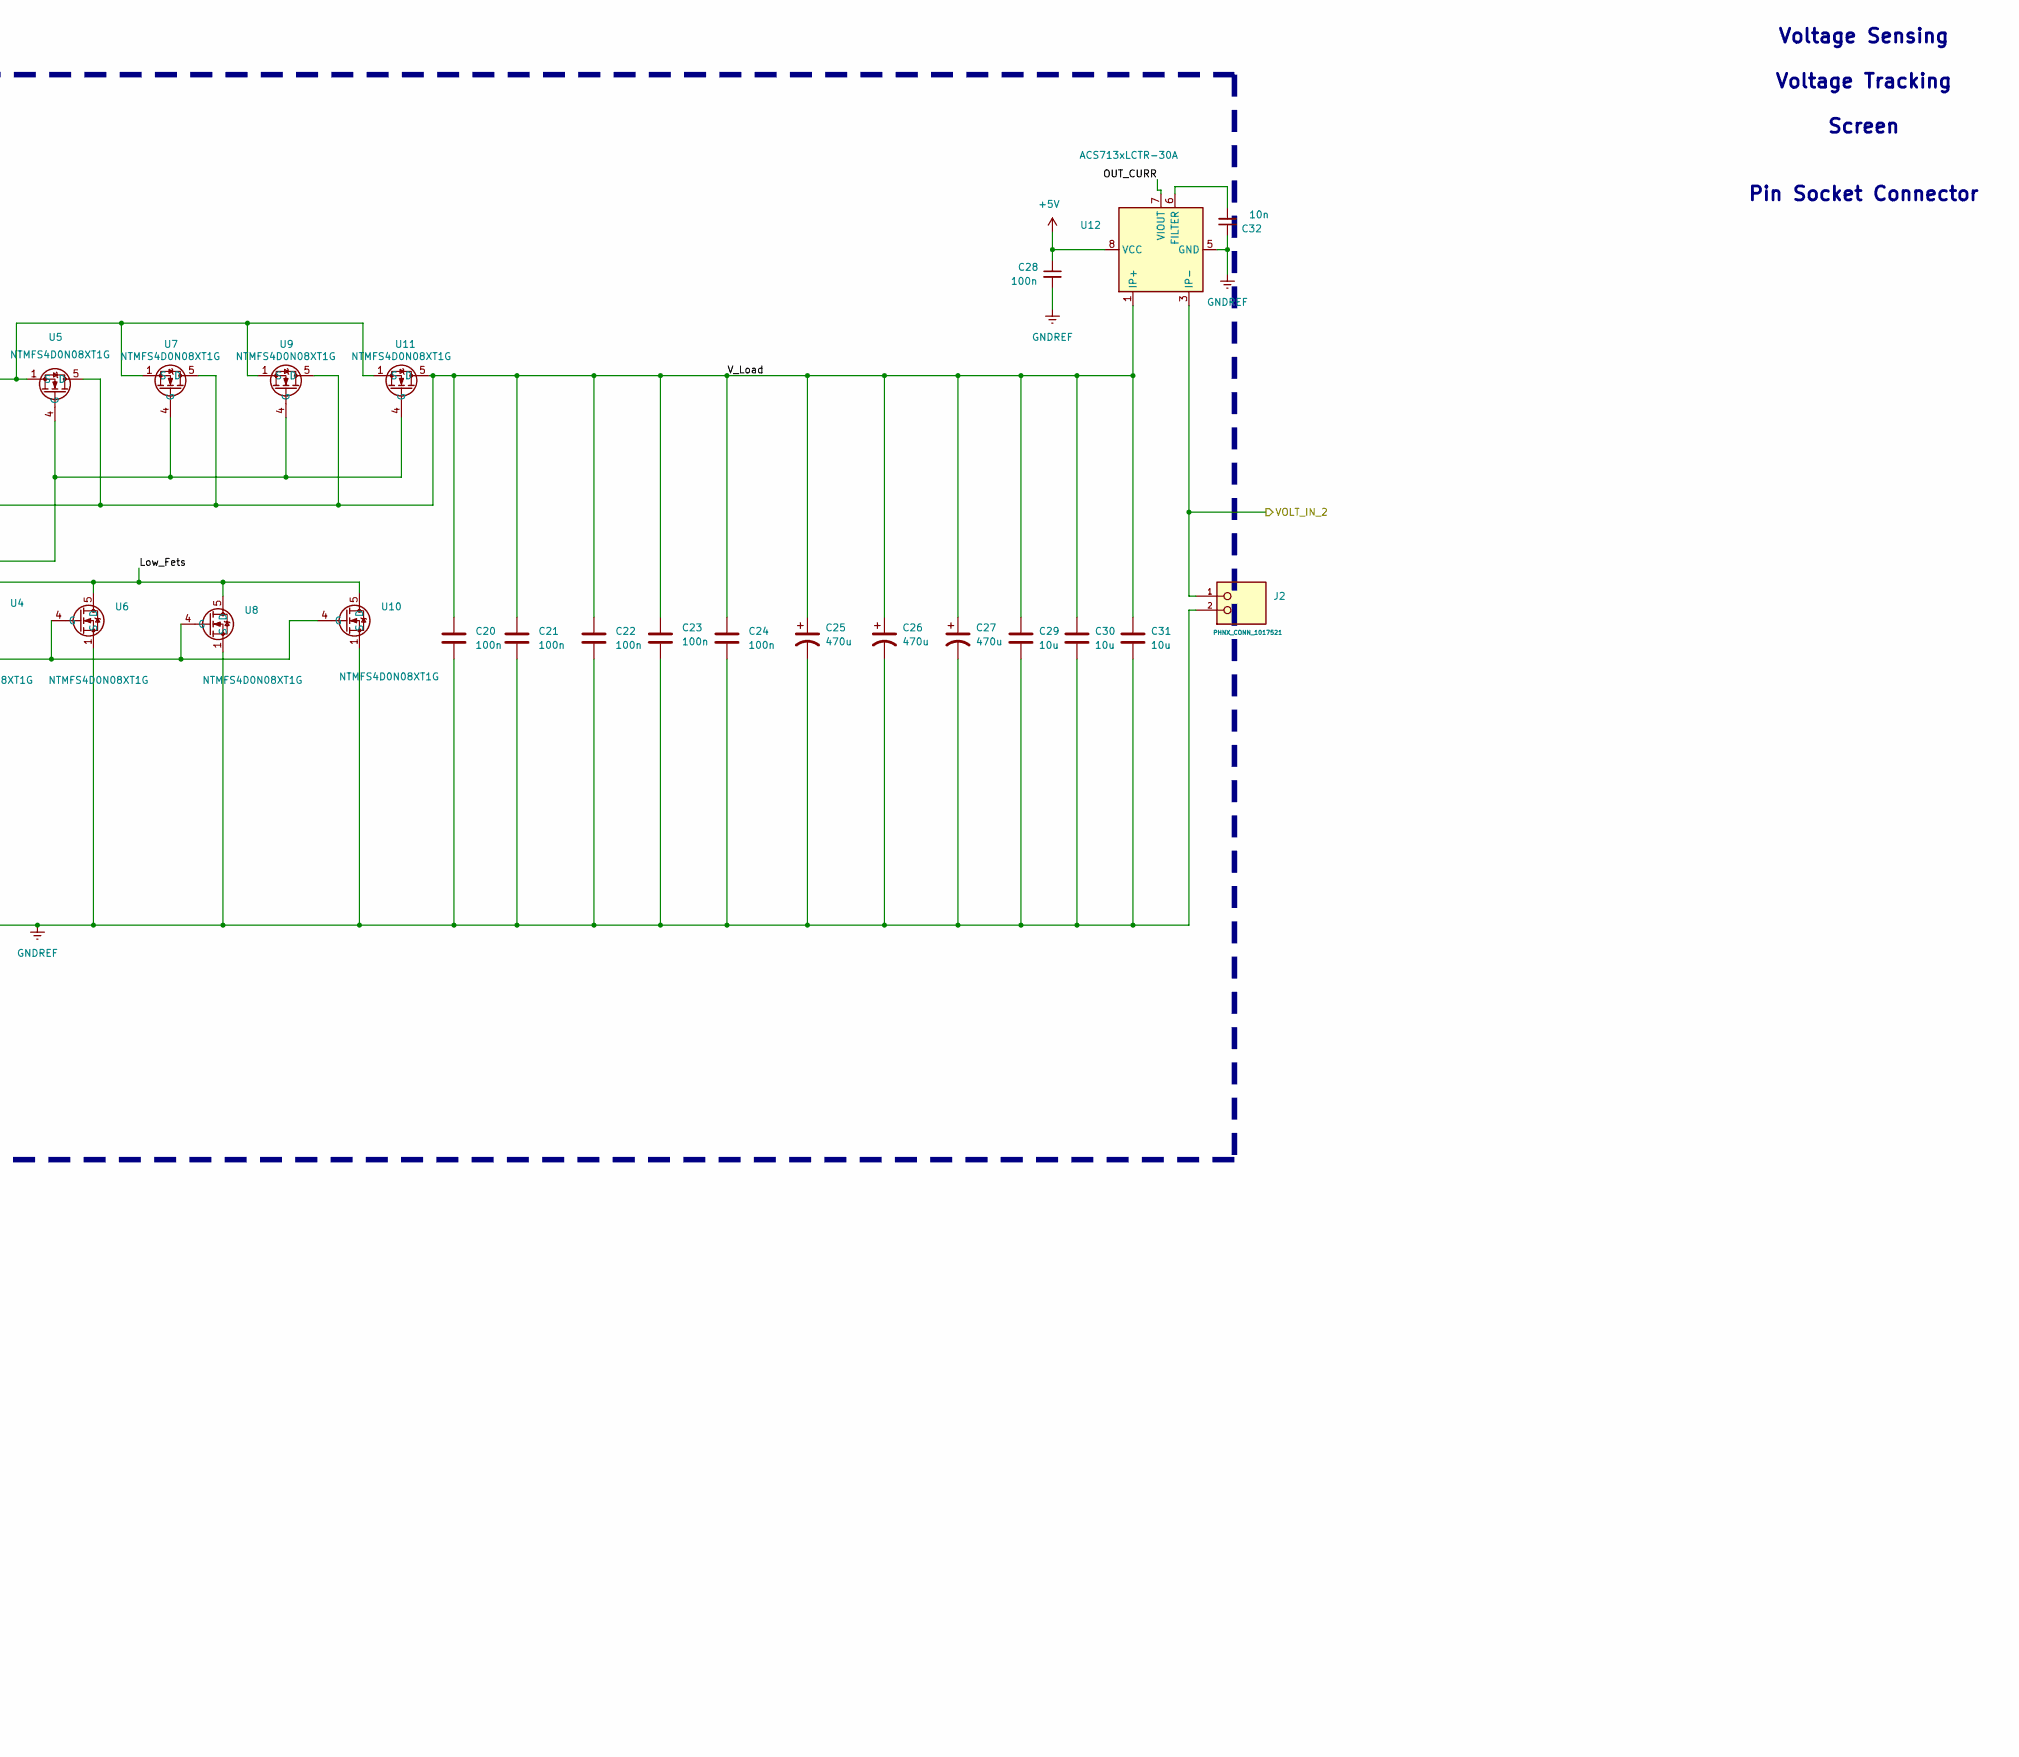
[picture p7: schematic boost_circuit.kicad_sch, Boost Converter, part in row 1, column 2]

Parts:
C1, C2, C3: 470u; CAP_PAN_10X20_PAN; Part # ECA-1HM471B
C4, C5, C6, C7: 22u; C_0805_2012Metric
C8, C9: 1u; C_0603_1608Metric
C10, C28: 100n; C_0603_1608Metric; Part# C88219
C11: 47u; C_0603_1608Metric
C12: 220p; C_0805_2012Metric
C13, C32: 10n; C_0603_1608Metric; Part# C88219
C14: 12n; C_0603_1608Metric
C15: 470p; C_0603_1608Metric; Rating 25V
C16: 0u1; C_0603_1608Metric
C17: 22u; C_0603_1608Metric
C18: 100n; R_0603_1608Metric
C19: 4u7; C_0603_1608Metric
C20, C21, C22, C23, C24: 100n; C_0603_1608Metric
C25, C26, C27: 470u; CAP_YX_16X31P5_RUB; Part # 100ZLH470MEFC16X31.5
C29, C30, C31: 10u; C_1210_3225Metric
D1, D2: MMSZ5226B-7-F; D_SOD_123_M; Part# C155250
J1, J2: PHNX_CONN_1017521; PHOENIX_1017521; PARTREV 04.01.2018
JP1: SolderJumper_3_Open; SolderJumper-3_P1.3mm_Open_RoundedPad1.0x1.5mm_NumberLabels
JP2: SolderJumper_2_Open; SolderJumper-2_P1.3mm_Open_RoundedPad1.0x1.5mm
L1: 2.2u; L_Kemet_3u3
NT1: NetTie_2; NetTie-2_SMD_Pad0.5mm
R1: 50k; R_0603_1608Metric
R2, R9, R10: 100k; R_0603_1608Metric
R3: 200k; R_0603_1608Metric; Part# C25811
R4: 15.4k; R_0603_1608Metric_Pad0.98x0.95mm_HandSolder
R5: 6k98; R_0603_1608Metric
R6: 28k; R_0603_1608Metric
R7: 25k; R_0603_1608Metric
R8: 200k; R_0603_1608Metric
R11: 0.750u; CSS2H3920RL700F
SW1, SW2: SW_SPDT; PinHeader_1x03_P2.54mm_Vertical
U1, U12: ACS713xLCTR-30A; SOIC-8_3.9x4.9mm_P1.27mm
U2: MCP6007; SOIC-8_3.9x4.9mm_P1.27mm
U3: LM51231QRGRRQ1; RGR0020C-MFG
U4, U5, U6, U7, U8, U9, U10, U11: NTMFS4D0N08XT1G; PowerMosDFNHybrid

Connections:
+5V: C10.1, C16.1, C28.1, U1.8 (VCC), U2.8 (V+), U12.8 (VCC); also elsewhere on the board
/Boost-Circuit/CSN: L1.1, R11.2, U3.2 (CSN)
/Boost-Circuit/CSP: C9.1, R11.1, SW1.3 (C), U1.3 (IP-), U1.4 (IP-), U3.1 (CSP), U3.8 (BIAS)
/Boost-Circuit/Enable_Pin: SW1.1 (A); also elsewhere on the board
/Boost-Circuit/INPUT_CURR: D1.1, U2.1, U2.2 (-); also elsewhere on the board
/Boost-Circuit/IN_CURR: R2.2, U1.7 (VIOUT)
/Boost-Circuit/Low_Fets: C18.1, L1.2, U3.6 (SW), U4.5 (D), U5.1 (S), U5.2 (S), U5.3 (S), U6.5 (D), U7.1 (S), U7.2 (S), U7.3 (S), U8.5 (D), U9.1 (S), U9.2 (S), U9.3 (S), U10.5 (D), U11.1 (S), U11.2 (S), U11.3 (S)
/Boost-Circuit/OUTPUT_CURR: D2.1, U2.6 (-), U2.7; also elsewhere on the board
/Boost-Circuit/OUT_CURR: R9.1, U12.7 (VIOUT)
/Boost-Circuit/TRK: R7.2; also elsewhere on the board
/Boost-Circuit/VOLT_IN_1: C1.1, C2.1, C3.1, C4.1, C5.1, C6.1, C7.1, C8.1, J1.1, U1.1 (IP+), U1.2 (IP+); also elsewhere on the board
/Boost-Circuit/VOLT_IN_2: J2.1, U12.3 (IP-), U12.4 (IP-); also elsewhere on the board
/Boost-Circuit/V_Load: C20.1, C21.1, C22.1, C23.1, C24.1, C25.1, C26.1, C27.1, C29.1, C30.1, C31.1, U3.3 (VOUT_SENSE), U5.5 (D), U7.5 (D), U9.5 (D), U11.5 (D), U12.1 (IP+), U12.2 (IP+)
/Boost-Circuit/Vcc: C19.1, JP1.3 (B), R10.2, U3.9 (VCC)
GND: C16.2, D1.2, D2.2, JP2.2 (B), R3.2, R8.2, U2.4 (V-); also elsewhere on the board
GNDA: C11.2, C12.2, C14.2, C15.2, C17.2, JP1.1 (A), NT1.2, R1.2, R6.2, U3.14 (SYNC_DITHER_VH)
GNDREF: C1.2, C2.2, C3.2, C4.2, C5.2, C6.2, C7.2, C8.2, C9.2, C10.2, C13.1, C19.2, C20.2, C21.2, C22.2, C23.2, C24.2, C25.2, C26.2, C27.2, C28.2, C29.2, C30.2, C31.2, C32.1, J1.2, J2.2, JP2.1 (A), NT1.1, U1.5 (GND), U3.10 (PGND), U3.19 (AGND), U3.21 (EP), U4.1 (S), U4.2 (S), U4.3 (S), U6.1 (S), U6.2 (S), U6.3 (S), U8.1 (S), U8.2 (S), U8.3 (S), U10.1 (S), U10.2 (S), U10.3 (S), U12.5 (GND)
unnamed: C14.1, R4.2
unnamed: JP1.2 (C), U3.12 (MODE)
unnamed: SW1.2 (B), U3.13 (UVLO_EN)
unnamed: C17.1, R7.1, SW2.1 (A)
unnamed: SW2.2 (B), U3.18 (TRK)
unnamed: R5.2, R6.1, SW2.3 (C)
unnamed: C13.2, U1.6 (FILTER)
unnamed: R2.1, R3.1, U2.3 (+)
unnamed: R8.1, R9.2, U2.5 (+)
unnamed: C12.1, R4.1, U3.20 (COMP)
unnamed: C18.2, U3.7 (HB)
unnamed: R10.1, U3.4 (PGOOD)
unnamed: R1.1, U3.15 (RT)
unnamed: C11.1, U3.17 (SS)
unnamed: C15.1, R5.1, U3.16 (VREF_RANGE)
unnamed: U3.11 (LO), U4.4 (G), U6.4 (G), U8.4 (G), U10.4 (G)
unnamed: U3.5 (HO), U5.4 (G), U7.4 (G), U9.4 (G), U11.4 (G)
unnamed: C32.2, U12.6 (FILTER)

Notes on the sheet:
used 27k
DC-BOOST CIRCUIT
Resistor Divider brings down max voltage of 4.5V from current sensor to 3V
470n
used 6.8k
Volt Dividers and LP Filters 3.0V = R2/(R1+R2)*4.5V R1 = 100k R2 = 200k
Time Constant for RC filter = 0.55s
Volt Dividers and LP Filters 2V = R2/(R1+R2)*2.5V R1 = 10k R2 = 40k
Current Sensing
GND PLANES NEED TO BE JUMPED IN ONE SPOT
Voltage Sensing Voltage Tracking Screen Pin Socket Connector
Designed around 25A being the max current possible
Find capacitor around 47 uF
Designed around 50A being the max current possible
Equivalent to 198 uF

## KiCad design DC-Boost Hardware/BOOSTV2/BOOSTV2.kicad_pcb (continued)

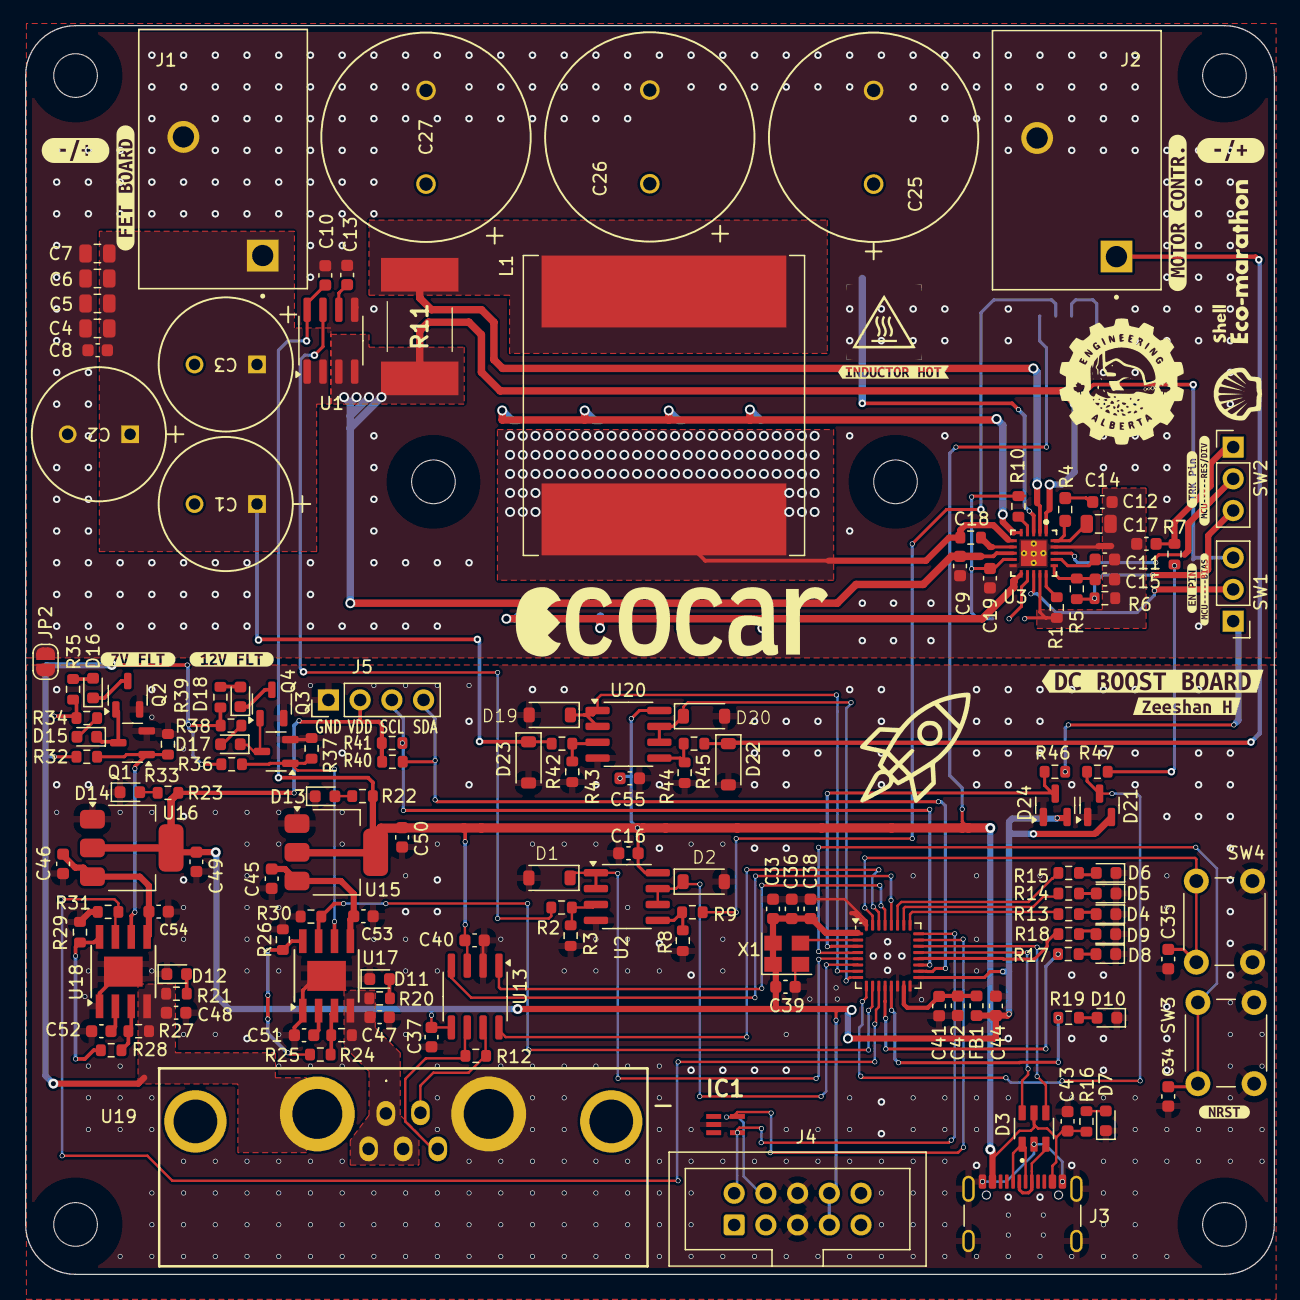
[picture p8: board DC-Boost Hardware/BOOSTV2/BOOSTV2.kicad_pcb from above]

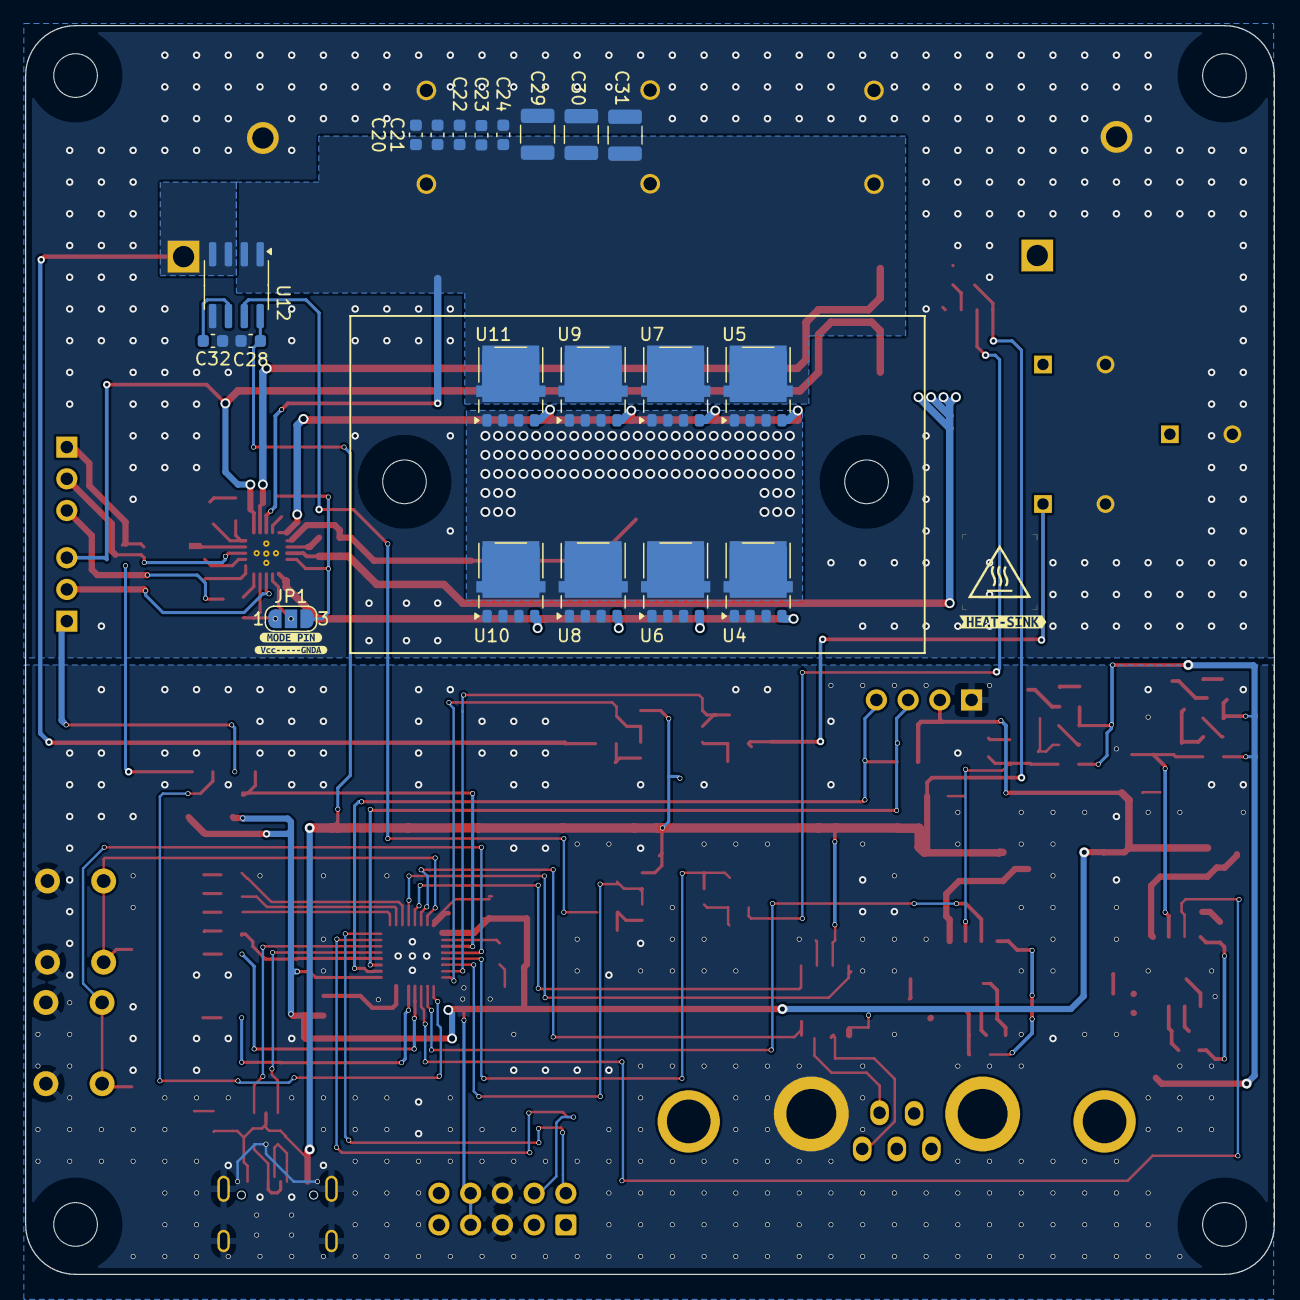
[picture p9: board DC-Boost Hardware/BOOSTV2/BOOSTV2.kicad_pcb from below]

Board: 2 copper layers, 100.0 x 100.0 mm, 189 parts (23 on the bottom side), 98 nets.

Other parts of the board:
kibuzzard-67B8F6AB: G***; kibuzzard-67B8F6AB
kibuzzard-67B8F68E: G***; kibuzzard-67B8F68E
kibuzzard-67B8F697: G***; kibuzzard-67B8F697
kibuzzard-67B37C45: G***; kibuzzard-67B37C45
kibuzzard-67B37DE2: G***; kibuzzard-67B37DE2
kibuzzard-67B58E6E: G***; kibuzzard-67B58E6E
kibuzzard-67B58E58: G***; kibuzzard-67B58E58
kibuzzard-67B540FD: G***; kibuzzard-67B540FD
kibuzzard-67B591A9: G***; kibuzzard-67B591A9
kibuzzard-67BA3C10: G***; kibuzzard-67BA3C10
kibuzzard-67BA360B: G***; kibuzzard-67BA360B
kibuzzard-67BA362A: G***; kibuzzard-67BA362A
kibuzzard-6743FE6D: G***; kibuzzard-6743FE6D
kibuzzard-6743FE8B: G***; kibuzzard-6743FE8B
kibuzzard-694398FD: G***; kibuzzard-694398FD
kibuzzard-67392652, kibuzzard-67392652#2: G***; kibuzzard-67392652

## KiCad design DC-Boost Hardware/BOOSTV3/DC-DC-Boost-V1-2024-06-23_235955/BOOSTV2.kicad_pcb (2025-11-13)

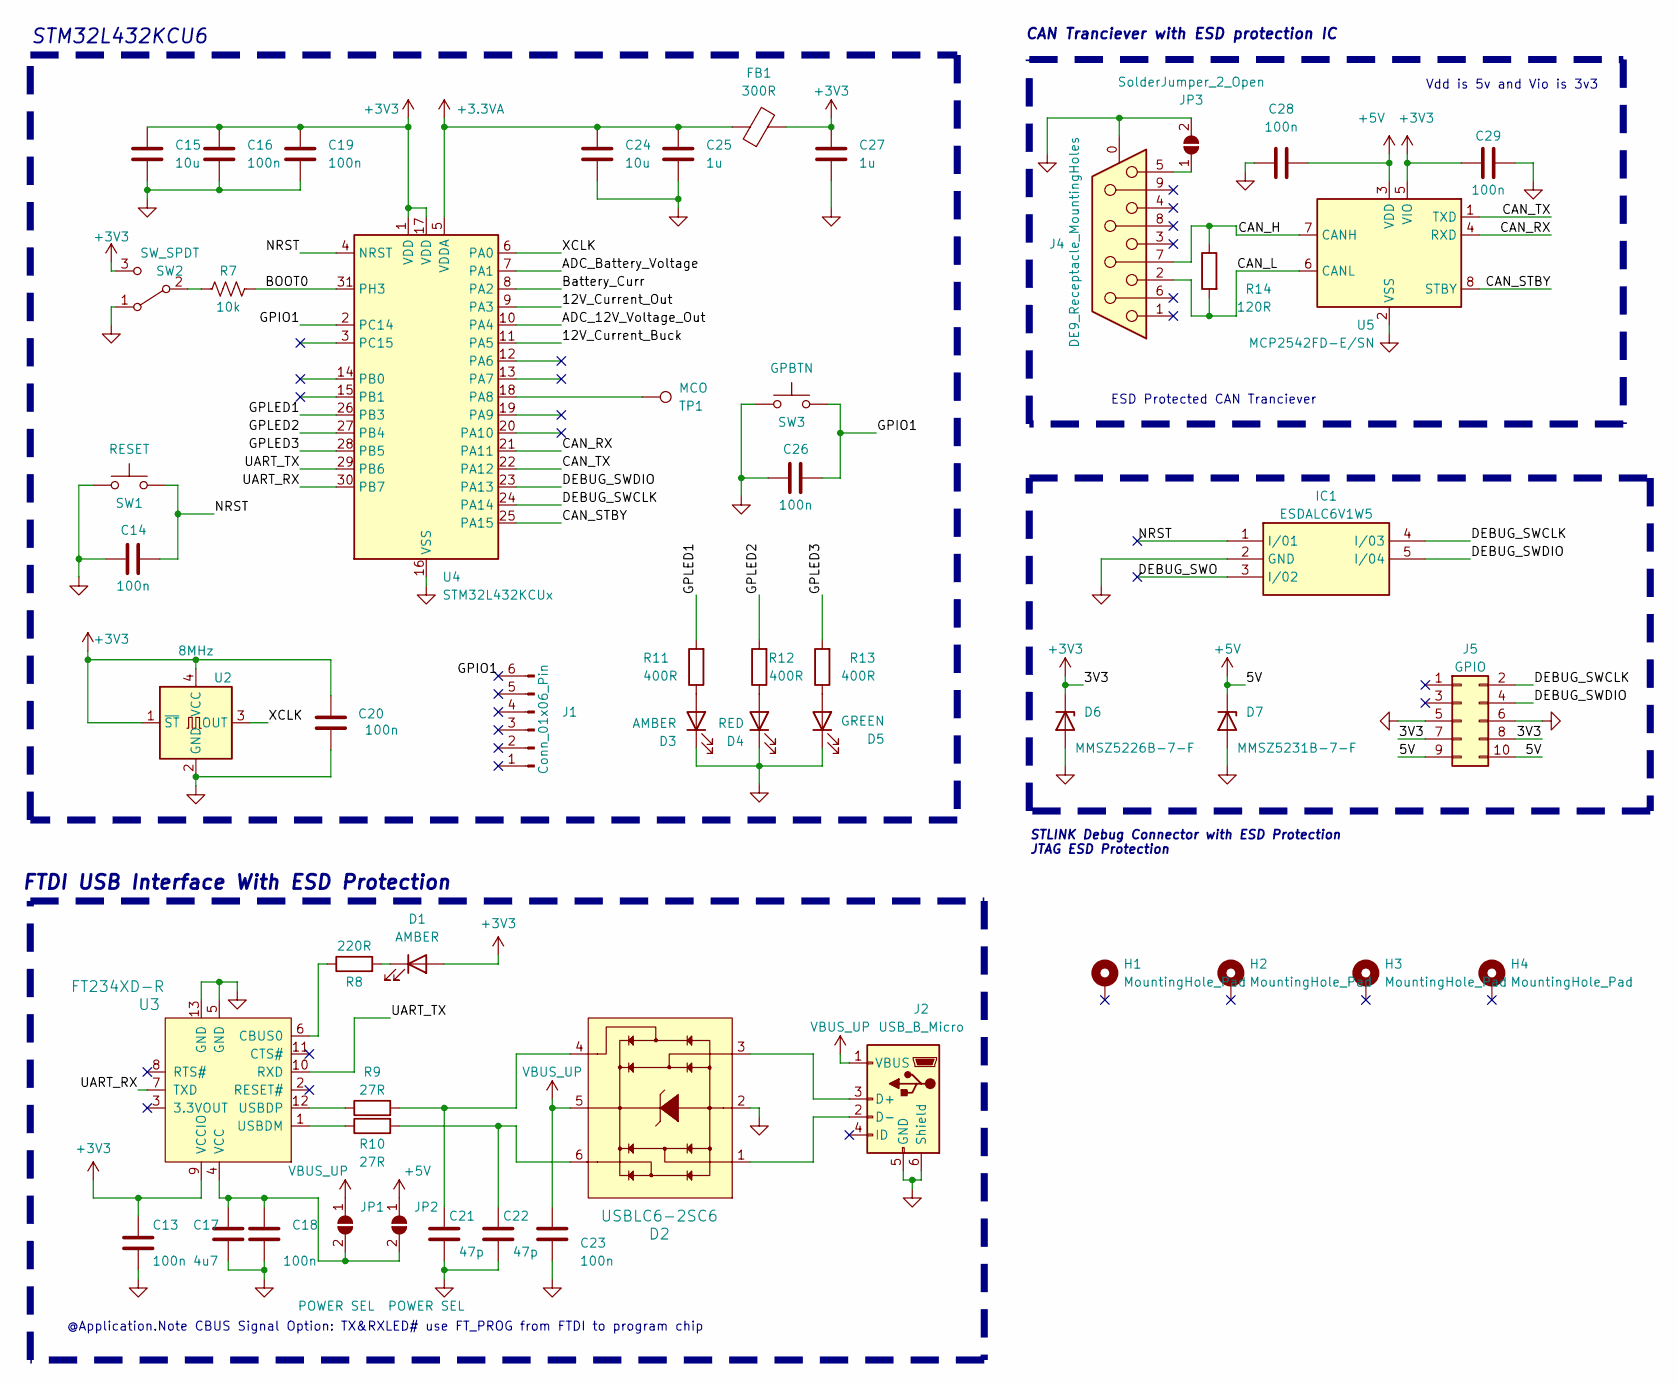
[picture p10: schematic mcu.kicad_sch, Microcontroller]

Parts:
C13, C14, C16, C18, C19, C20, C23, C26, C28, C29: 100n; C_0402_1005Metric; JLCPCB Part#(Optional) C1525
C15, C24: 10u; C_0603_1608Metric; JLCPCB Part#(Optional) C96446
C17: 4u7; C_0603_1608Metric; JLCPCB Part#(Optional) C1779
C21, C22: 47p; C_0402_1005Metric; JLCPCB Part#(Optional) C1671
C25, C27: 1u; C_0603_1608Metric; JLCPCB Part#(Optional) C28323
D1, D3: AMBER; LED_0805_2012Metric; JLCPCB Part#(Optional) C2296
D2: USBLC6-2SC6; SOT95P280X145-6N; Digikey # 497-5235-1-ND
D4: RED; LED_0805_2012Metric; JLCPCB Part#(Optional) C84256
D5: GREEN; LED_0805_2012Metric; JLCPCB Part#(Optional) C2297
D6: MMSZ5226B-7-F; D_SOD-123; Digikey # MMSZ5226B-FDICT-ND
D7: MMSZ5231B-7-F; D_SOD-123; Digikey # MMSZ5231B-7-F
FB1: 300R; L_0603_1608Metric; Digikey # 1934-1474-1-ND
H1, H2, H3, H4: MountingHole_Pad; MountingHole_3.2mm_M3_Pad
IC1: ESDALC6V1W5; SOT65P210X110-5N; JLCPCB Part#(Optional) C2827626
J1: Conn_01x06_Pin; PinHeader_2x03_P2.54mm_Vertical
J2: USB_B_Micro; USB_Micro-B_Amphenol_10118194_Horizontal; Digikey # 609-4618-1-ND
J4: DE9_Receptacle_MountingHoles; DSUB-9_Female_Horizontal_P2.77x2.84mm_EdgePinOffset7.70mm_H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
J5: GPIO; PinHeader_2x05_P2.54mm_Vertical; JLCPCB Part#(Optional) C5116482
JP1, JP2: POWER SEL; SolderJumper-2_P1.3mm_Open_TrianglePad1.0x1.5mm
JP3: SolderJumper_2_Open; SolderJumper-2_P1.3mm_Open_RoundedPad1.0x1.5mm
R7: 10k; R_0805_2012Metric; JLCPCB Part#(Optional) C17414
R8: 220R; R_0805_2012Metric; JLCPCB Part#(Optional) C17557
R9, R10: 27R; R_0402_1005Metric; JLCPCB Part#(Optional) C25190
R11, R12, R13: 400R; R_0805_2012Metric; JLCPCB Part#(Optional) C17655
R14: 120R; R_0603_1608Metric
SW1: RESET; SW_PUSH_6mm_H5mm
SW2: SW_SPDT; SW_SPDT_PCM12; Digikey # 2223-SLW-66527511-SMT-TRCT-ND
SW3: GPBTN; SW_PUSH_6mm_H5mm
TP1: MCO; TestPoint_Pad_D1.0mm
U2: 8MHz; Crystal_SMD_3225-4Pin_3.2x2.5mm; Digikey # 535-ASE-8.000MHZ-L-C-TCT-ND
U3: FT234XD-R; SON45P300X300X80-13N; JLCPCB Part#(Optional) C132158
U4: STM32L432KCUx; QFN-32-1EP_5x5mm_P0.5mm_EP3.45x3.45mm; JLCPCB Part#(Optional) C1337280
U5: MCP2542FD-E/SN; SOIC-8_3.9x4.9mm_P1.27mm; Digikey # MCP2542FD-E/SN-ND

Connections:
+3.3VA: C24.1, C25.1, FB1.1, U4.5 (VDDA)
+3V3: C13.1, C15.1, C16.1, C19.1, C20.2, C27.1, C29.2, D1.2 (A), D6.1 (K), FB1.2, J5.7, J5.8, SW2.3 (C), U2.1 (~ST), U2.4 (VCC), U3.9 (VCCIO), U4.1 (VDD), U4.17 (VDD), U5.5 (VIO)
+5V: C28.2, D7.1 (K), J5.9, J5.10, JP2.1 (A), U5.3 (VDD)
/MCU/12V_Current_Buck: U4.11 (PA5)
/MCU/12V_Current_Out: U4.9 (PA3)
/MCU/ADC_12V_Voltage_Out: U4.10 (PA4)
/MCU/ADC_Battery_Voltage: U4.7 (PA1)
/MCU/BOOT0: R7.2, U4.31 (PH3)
/MCU/Battery_Curr: U4.8 (PA2)
/MCU/CAN_H: J4.7, R14.1, U5.7 (CANH)
/MCU/CAN_L: J4.2, R14.2, U5.6 (CANL)
/MCU/CAN_RX: U4.21 (PA11), U5.4 (RXD)
/MCU/CAN_STBY: U4.25 (PA15), U5.8 (STBY)
/MCU/CAN_TX: U4.22 (PA12), U5.1 (TXD)
/MCU/DEBUG_SWCLK: IC1.4 (I/03), J5.2, U4.24 (PA14)
/MCU/DEBUG_SWDIO: IC1.5 (I/04), J5.4, U4.23 (PA13)
/MCU/DEBUG_SWO: IC1.3 (I/02)
/MCU/GPIO1: C26.2, J1.6, SW3.2, U4.2 (PC14)
/MCU/GPLED1: R11.2, U4.26 (PB3)
/MCU/GPLED2: R12.2, U4.27 (PB4)
/MCU/GPLED3: R13.2, U4.28 (PB5)
/MCU/NRST: C14.2, IC1.1 (I/01), SW1.2, U4.4 (NRST)
/MCU/UART_RX: U3.7 (TXD), U4.30 (PB7)
/MCU/UART_TX: U3.10 (RXD), U4.29 (PB6)
/MCU/XCLK: U2.3 (OUT), U4.6 (PA0)
GND: C13.2, C14.1, C15.2, C16.2, C17.2, C18.2, C19.2, C20.1, C21.1, C22.1, C23.1, C24.2, C25.2, C26.1, C27.2, C28.1, C29.1, D2.2, D3.1 (K), D4.1 (K), D5.1 (K), D6.2 (A), D7.2 (A), IC1.2 (GND), J2.5 (GND), J2.6 (Shield), J4.0 (PAD), J5.5, J5.6, JP3.2 (B), SW1.1, SW2.1 (A), SW3.1, U2.2 (GND), U3.5 (GND), U3.13 (GND), U4.16 (VSS), U4.32 (VSS), U4.33 (VSS), U5.2 (VSS), U5.9 (VSS); also elsewhere on the board
unnamed: C21.2, D2.4, R9.2
unnamed: C22.2, D2.6, R10.2
unnamed: D1.1 (K), R8.2
unnamed: D3.2 (A), R11.1
unnamed: D4.2 (A), R12.1
unnamed: D5.2 (A), R13.1
unnamed: D2.3, J2.3 (D+)
unnamed: D2.1, J2.2 (D-)
unnamed: C17.1, C18.1, JP1.2 (B), JP2.2 (B), U3.4 (VCC)
unnamed: J4.5, JP3.1 (A)
unnamed: R7.1, SW2.2 (B)
unnamed: R8.1, U3.6 (CBUS0)
unnamed: R10.1, U3.1 (USBDM)
unnamed: R9.1, U3.12 (USBDP)
unnamed: TP1.1, U4.18 (PA8)
VBUS_UP: C23.2, D2.5, J2.1 (VBUS), JP1.1 (A)

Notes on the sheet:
@Application.Note CBUS Signal Option: TX&RXLED# use FT_PROG from FTDI to program chip
ESD Protected CAN Tranciever
Vdd is 5v and Vio is 3v3
STM32L432KCU6
CAN Tranciever with ESD protection IC
FTDI USB Interface With ESD Protection
STLINK Debug Connector with ESD Protection JTAG ESD Protection

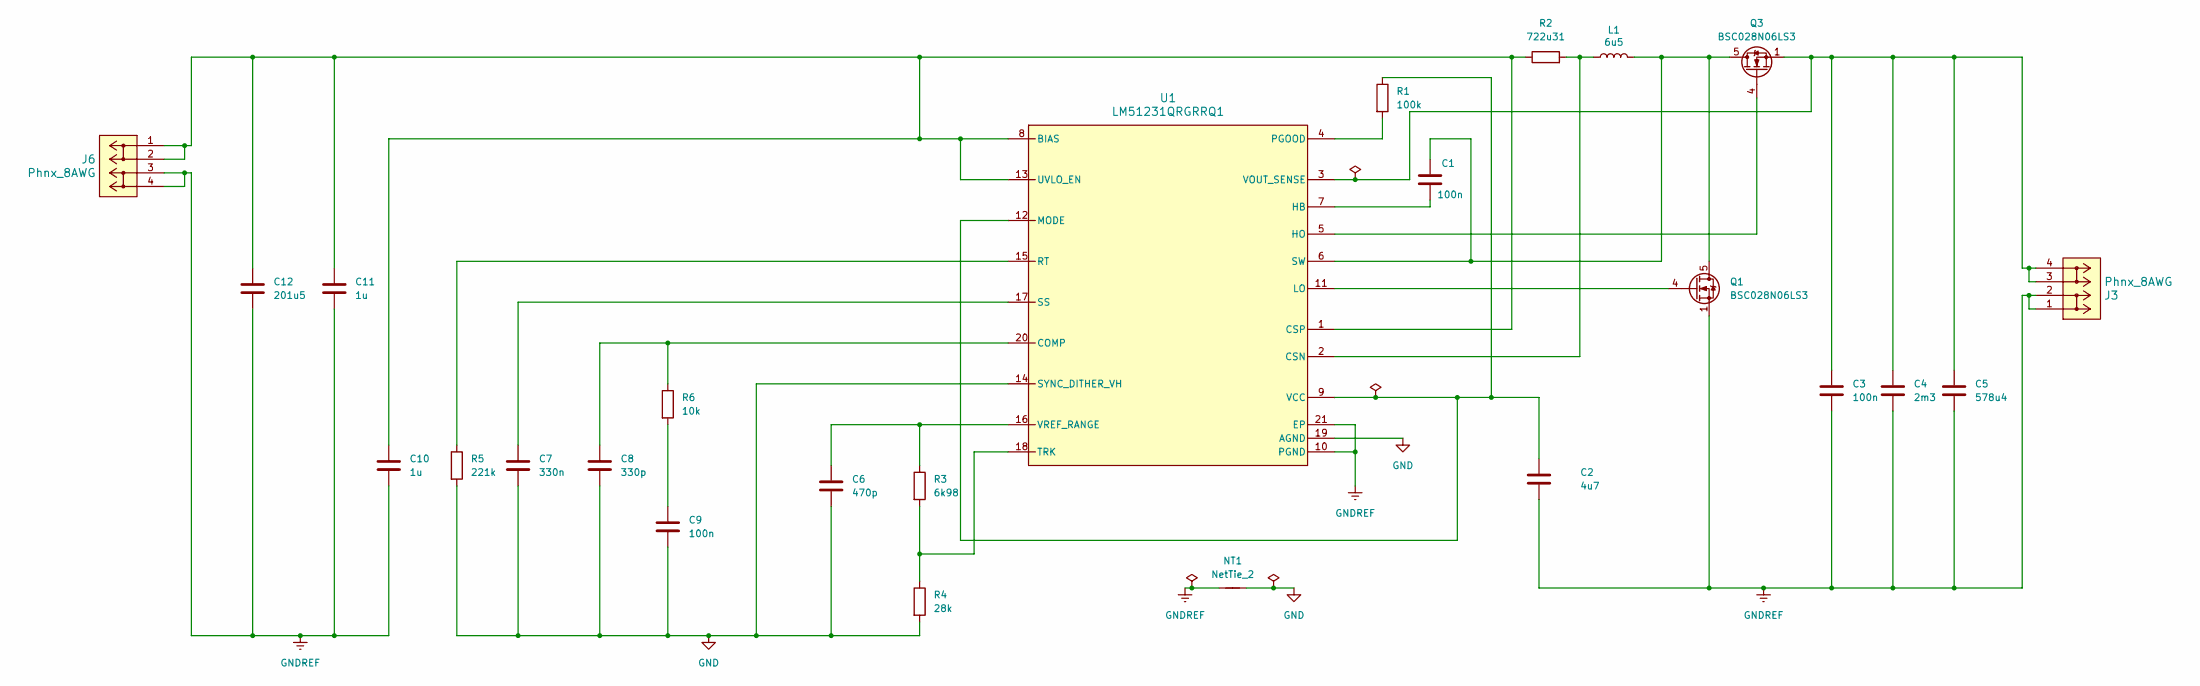
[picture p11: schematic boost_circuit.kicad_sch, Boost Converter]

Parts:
C1, C3, C9: 100n; C_0402_1005Metric
C2: 4u7; C_0402_1005Metric
C4: 2m3; CP_Radial_D18.0mm_P7.50mm
C5: 578u4; CAPPRD500W85D1250H3700
C6: 470p; C_0402_1005Metric
C7: 330n; C_0603_1608Metric
C8: 330p; C_0805_2012Metric
C10: 1u; C_0603_1608Metric
C11: 1u; C_0402_1005Metric
C12: 201u5; CAP_EEE1HA221P
J3, J6: Phnx_8AWG; CONN_VP0265x4xxxxG_AMP; Part# VP0265540000G-ND
L1: 6u5; L_Bourns_SRR1208_12.7x12.7mm
NT1: NetTie_2
Q1, Q3: BSC028N06LS3; TDSON-8-1
R1: 100k; R_0603_1608Metric
R2: 722u31; CSS2H3920RL700F
R3: 6k98; R_0402_1005Metric
R4: 28k; R_0402_1005Metric
R5: 221k; R_0603_1608Metric
R6: 10k; R_0201_0603Metric
U1: LM51231QRGRRQ1; RGR0020C-MFG

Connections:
GND: C6.2, C7.2, C8.2, C9.2, NT1.2, R4.2, R5.2, U1.14 (SYNC_DITHER_VH), U1.19 (AGND); also elsewhere on the board
GNDREF: C2.2, C3.2, C4.2, C5.2, C10.2, C11.2, C12.2, J3.1, J3.2, J6.3, J6.4, NT1.1, Q1.1 (S), Q1.2 (S), Q1.3 (S), U1.10 (PGND), U1.21 (EP)
unnamed: C9.1, R6.2
unnamed: C1.1, L1.2, Q1.5 (D), Q3.5 (D), U1.6 (SW)
unnamed: Q1.4 (G), U1.11 (LO)
unnamed: Q3.4 (G), U1.5 (HO)
unnamed: C10.1, C11.1, C12.1, J6.1, J6.2, R2.1, U1.1 (CSP), U1.8 (BIAS), U1.13 (UVLO_EN)
unnamed: C8.1, R6.1, U1.20 (COMP)
unnamed: L1.1, R2.2, U1.2 (CSN)
unnamed: C1.2, U1.7 (HB)
unnamed: C2.1, R1.1, U1.9 (VCC), U1.12 (MODE)
unnamed: R1.2, U1.4 (PGOOD)
unnamed: R5.1, U1.15 (RT)
unnamed: C7.1, U1.17 (SS)
unnamed: R3.2, R4.1, U1.18 (TRK)
unnamed: C3.1, C4.1, C5.1, J3.3, J3.4, Q3.1 (S), Q3.2 (S), Q3.3 (S), U1.3 (VOUT_SENSE)
unnamed: C6.1, R3.1, U1.16 (VREF_RANGE)

Board: 2 copper layers, 77 parts (0 on the bottom side), 52 nets, no tracks yet.

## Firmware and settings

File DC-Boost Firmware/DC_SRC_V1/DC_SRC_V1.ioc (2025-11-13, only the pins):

Mcu.UserName=STM32G491KEUx
PA0.GPIO_Label=INPUT_CURR
PA0.Signal=ADC1_IN1
PA1.GPIO_Label=OUTPUT_CURR
PA1.Signal=ADC1_IN2
PA10.GPIO_Label=LED4
PA10.Signal=S_TIM1_CH3
PA11.GPIO_Label=USB_D-
PA11.Signal=USB_DM
PA12.GPIO_Label=USB_D+
PA12.Signal=USB_DP
PA13.Signal=SYS_JTMS-SWDIO
PA14.Signal=SYS_JTCK-SWCLK
PA15.GPIO_Label=LED3
PA15.Signal=S_TIM8_CH1
PA2.GPIO_Label=ISO_VOLT_INPUT_TERMINAL
PA2.Signal=ADC1_IN3
PA3.GPIO_Label=ISO_VOLT_OUTPUT_TERMINAL
PA3.Signal=ADC1_IN4
PA4.Signal=COMP_DAC11_group
PA5.GPIO_Label=ADC_12V_ILM
PA5.Signal=ADC2_IN13
PA6.GPIO_Label=ADC_7V_ILM
PA6.Signal=ADC2_IN3
PA7.GPIO_Label=LED5
PA7.Signal=S_TIM3_CH2
PA8.GPIO_Label=OLED_SDA
PA8.Signal=I2C2_SDA
PA9.GPIO_Label=OLED_SCL
PA9.Signal=I2C2_SCL
PB0.GPIO_Label=CAN_LED
PB0.Signal=S_TIM3_CH3
PB3.GPIO_Label=LED2
PB3.Signal=S_TIM2_CH2
PB4.GPIO_Label=LED1
PB4.Signal=S_TIM3_CH1
PB5.Signal=FDCAN2_RX
PB6.Signal=FDCAN2_TX
PB7.GPIO_Label=CAN_STBY
PB7.Signal=GPIO_Output
PB8-BOOT0.GPIO_Label=Toggle
PB8-BOOT0.Signal=GPIO_Input
PF0-OSC_IN.Signal=RCC_OSC_IN
PF1-OSC_OUT.GPIO_Label=ENABLE
PF1-OSC_OUT.Signal=GPIO_Output

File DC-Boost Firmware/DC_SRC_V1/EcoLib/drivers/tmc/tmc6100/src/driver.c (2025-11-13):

/*
 * driver.c
 *
 *  Created on: Jan 30, 2025
 *      Author: abina
 */
#include "driver.h"
#include "main.h"

int driver_initialize(driver_t *drv) {

}

int driver_spi_read(driver_t *drv, uint8_t reg_addr, uint32_t *read_result) {

	HAL_GPIO_WritePin(drv->driver_nss_port, drv->driver_nss_pin,
			GPIO_PIN_RESET);

	uint8_t prepped_buffer = (uint8_t) reg_addr | 0x7f;

	if (!HAL_SPI_Transmit(drv->hspi, prepped_buffer, 1, HAL_MAX_DELAY)
			!= HAL_OK) {
		LOG_ERROR("Failed to read register 0x%x", reg_addr);
	}

	if (!HAL_SPI_Receive(drv->hspi, read_result, 4, HAL_MAX_DELAY) != HAL_OK) {
		LOG_ERROR("Failed to read register 0x%x", reg_addr);
	}

	HAL_GPIO_WritePin(drv->driver_nss_port, drv->driver_nss_pin, GPIO_PIN_SET);
}

int driver_spi_write(driver_t *drv, uint8_t reg_addr, uint8_t write_data[]) {

	// 1 the MSB since that is the wnr bit. we are writing so it must be 1.
	uint8_t prep_register_buffer[5] = { ((uint8_t) reg_addr | 0x80u),
			rf_register_value };

	HAL_GPIO_WritePin(drv->driver_nss_port, drv->driver_nss_pin,
			GPIO_PIN_RESET);

	if (HAL_SPI_Transmit(rf_handle->rf_spi_handle, prep_register_buffer, 2,
			rf_handle->rf_spi_timeout) != HAL_OK) {
		LOG_ERROR("Failed to set register 0x%x : 0x%x", rf_register_address,
				rf_register_value);
		return 0;
	}

	HAL_GPIO_WritePin(drv->driver_nss_port, drv->driver_nss_pin, GPIO_PIN_SET);
}

int driver_enable_bridges(driver_t *drv, int enable) {

}

int driver_reset(driver_t *drv) {

}

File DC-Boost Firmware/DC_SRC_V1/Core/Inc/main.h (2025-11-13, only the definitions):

#define ENABLE_Pin GPIO_PIN_1
#define ENABLE_GPIO_Port GPIOF
#define INPUT_CURR_Pin GPIO_PIN_0
#define INPUT_CURR_GPIO_Port GPIOA
#define OUTPUT_CURR_Pin GPIO_PIN_1
#define OUTPUT_CURR_GPIO_Port GPIOA
#define ISO_VOLT_INPUT_TERMINAL_Pin GPIO_PIN_2
#define ISO_VOLT_INPUT_TERMINAL_GPIO_Port GPIOA
#define ISO_VOLT_OUTPUT_TERMINAL_Pin GPIO_PIN_3
#define ISO_VOLT_OUTPUT_TERMINAL_GPIO_Port GPIOA
#define ADC_12V_ILM_Pin GPIO_PIN_5
#define ADC_12V_ILM_GPIO_Port GPIOA
#define ADC_7V_ILM_Pin GPIO_PIN_6
#define ADC_7V_ILM_GPIO_Port GPIOA
#define LED5_Pin GPIO_PIN_7
#define LED5_GPIO_Port GPIOA
#define CAN_LED_Pin GPIO_PIN_0
#define CAN_LED_GPIO_Port GPIOB
#define OLED_SDA_Pin GPIO_PIN_8
#define OLED_SDA_GPIO_Port GPIOA
#define OLED_SCL_Pin GPIO_PIN_9
#define OLED_SCL_GPIO_Port GPIOA
#define LED4_Pin GPIO_PIN_10
#define LED4_GPIO_Port GPIOA
#define USB_D__Pin GPIO_PIN_11
#define USB_D__GPIO_Port GPIOA
#define USB_D_A12_Pin GPIO_PIN_12
#define USB_D_A12_GPIO_Port GPIOA
#define LED3_Pin GPIO_PIN_15
#define LED3_GPIO_Port GPIOA
#define LED2_Pin GPIO_PIN_3
#define LED2_GPIO_Port GPIOB
#define LED1_Pin GPIO_PIN_4
#define LED1_GPIO_Port GPIOB
#define CAN_STBY_Pin GPIO_PIN_7
#define CAN_STBY_GPIO_Port GPIOB
#define Toggle_Pin GPIO_PIN_8
#define Toggle_GPIO_Port GPIOB

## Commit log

2025-11-13 made repo
    [BOOSTV2.kicad_pcb]
2025-11-14 Initialize README with project details and guidelines
    Added detailed project description, features, and usage instructions for the DC Boost Board.
2025-12-18 README update
    Removed sections on electrical design, calibration, and safety.

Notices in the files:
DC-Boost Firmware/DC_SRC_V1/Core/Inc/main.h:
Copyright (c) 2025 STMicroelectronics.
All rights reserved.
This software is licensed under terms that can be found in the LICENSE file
